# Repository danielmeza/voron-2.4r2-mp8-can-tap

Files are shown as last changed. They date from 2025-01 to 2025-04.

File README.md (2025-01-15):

# voron-2.4r2-mp8-can-tap
Klipper configuration for the Voron 2.4r2 Formbot kit with BTT RP2040, and TAP.

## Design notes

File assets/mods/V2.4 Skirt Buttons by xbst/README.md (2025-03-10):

# Voron V2.4 Skirt Buttons Mod
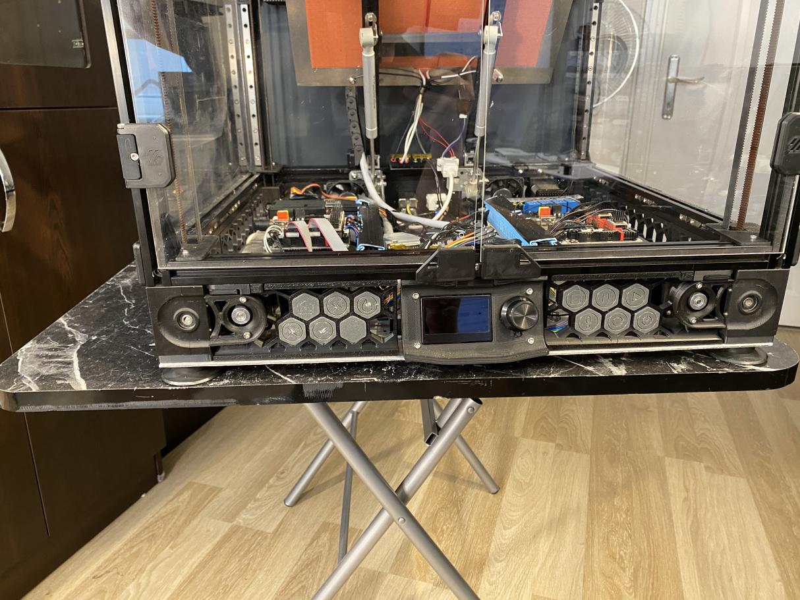
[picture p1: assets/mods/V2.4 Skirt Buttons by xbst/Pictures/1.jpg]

## Switches Needed
|Printer Size| Qty Needed |
|--|--|
| 350 | 12 |
| 300 | 8 |
| 250 | 4 |

You need 12*12mm 5mm tactile switches. Make sure they are through hole, not SMD! Here are a few examples:
Amazon: https://amzn.to/3788dfZ
Aliexpress: https://s.click.aliexpress.com/e/_eKCJlo

## Wiring
Put the switches in the hexagons, bend the legs of the switches.
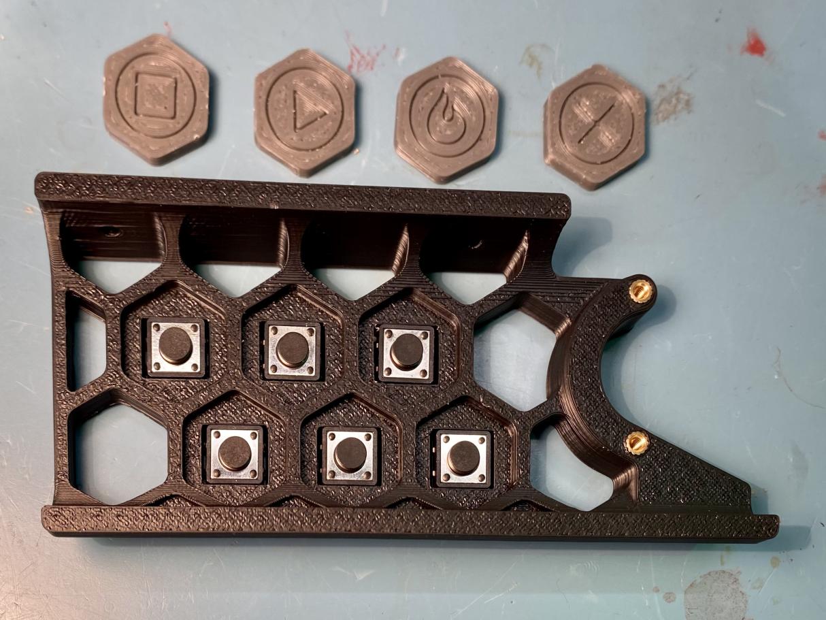
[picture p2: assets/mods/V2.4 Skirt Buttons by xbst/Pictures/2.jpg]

Wire one side of the switches together, connect to the mcu or Pi (depending on your config). Connect seperate wires to the opposite sides.
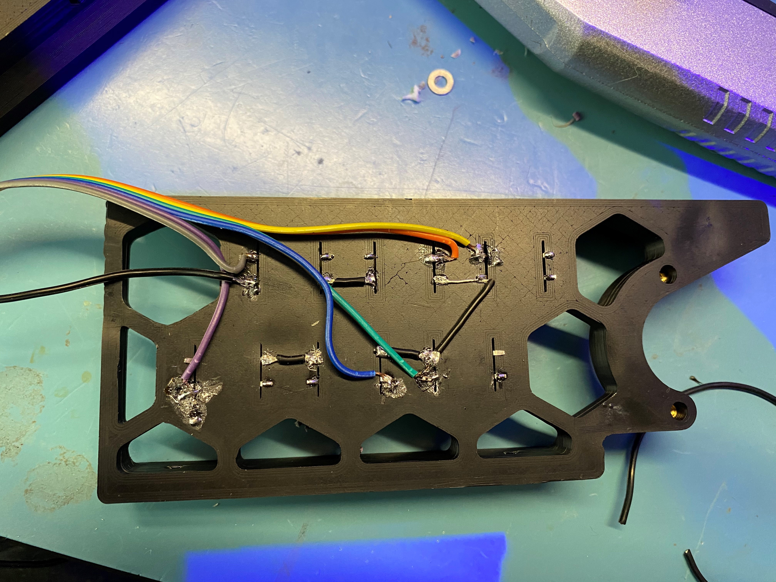
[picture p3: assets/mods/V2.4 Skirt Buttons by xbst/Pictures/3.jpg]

I recommend using hot glue to keep the wires in place. Otherwise you may disconnect the solder joints, or worse, break the legs of the switches when installing by accident.
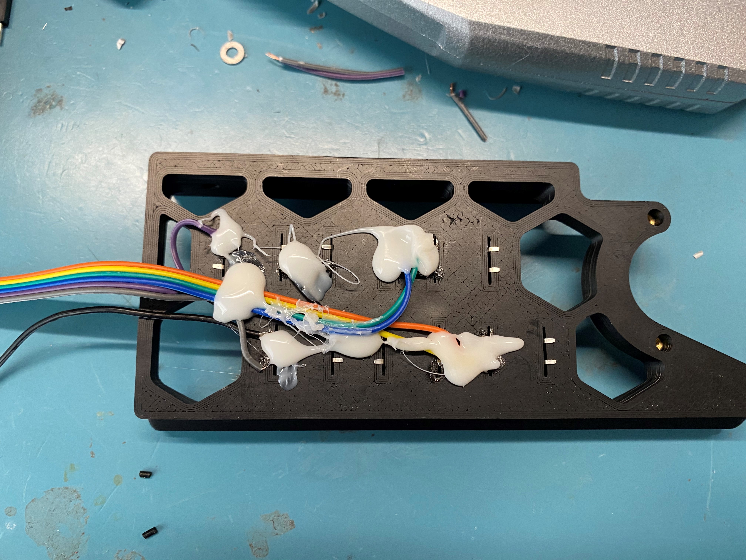
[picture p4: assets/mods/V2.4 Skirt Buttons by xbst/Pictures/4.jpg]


## Gluing The Buttons
I recommend using hot glue for attaching the printed button caps to the switches. You can also use super glue, but you may need to space the caps by putting a washer in between as hot glue is thicker.

You may need to cut the elephant foot if the buttons get stuck when pressed.

## Config Options
You have 2 choices: Using FW of your 3D printer (like Klipper), or using Octoprint's Enclosure plugin.

### Config for Klipper
Here is the relevant config info from [GitHub page of Klipper](https://github.com/KevinOConnor/klipper/blob/master/config/example-extras.cfg).

    # Execute gcode when a button is pressed or released (or when a pin
    # changes state). You can check the state of the button by using
    # QUERY_BUTTON button=my_gcode_button
    #[gcode_button my_gcode_button]
    #pin:
    # The pin on which the button is connected. This parameter must be
    # provided.
     #press_gcode:
    # A list of G-Code commands to execute when the button is pressed.
    # G-Code templates are supported. This parameter must be provided.
    #release_gcode:
    # A list of G-Code commands to execute when the button is released.
    # G-Code templates are supported. The default is to not run any
    # commands on a button release.

### Config for Octoprint
1. Install the plugin "Enclosure Plugin"
2. Configure based on the info on this page: https://github.com/vitormhenrique/OctoPrint-Enclosure

## Icons used
 https://www.iconfinder.com/iconsets/arrows-elements-outline
 Licensed under: https://creativecommons.org/licenses/by/3.0/

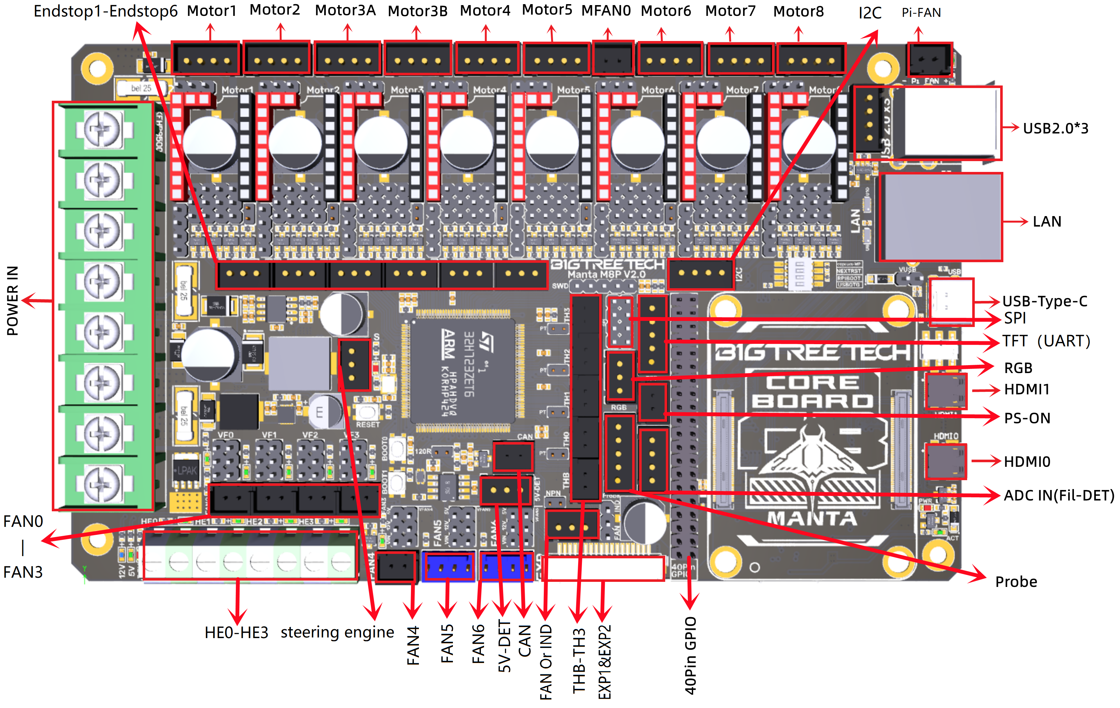
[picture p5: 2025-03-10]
docs/Manta MP8 v2/M8P V2.0-connect.png

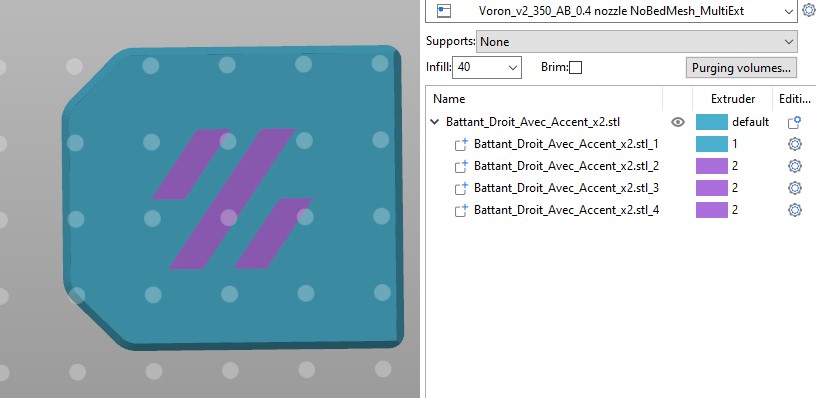
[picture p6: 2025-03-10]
assets/mods/Removable Doors by ElPoPo/Images/MMU.jpg

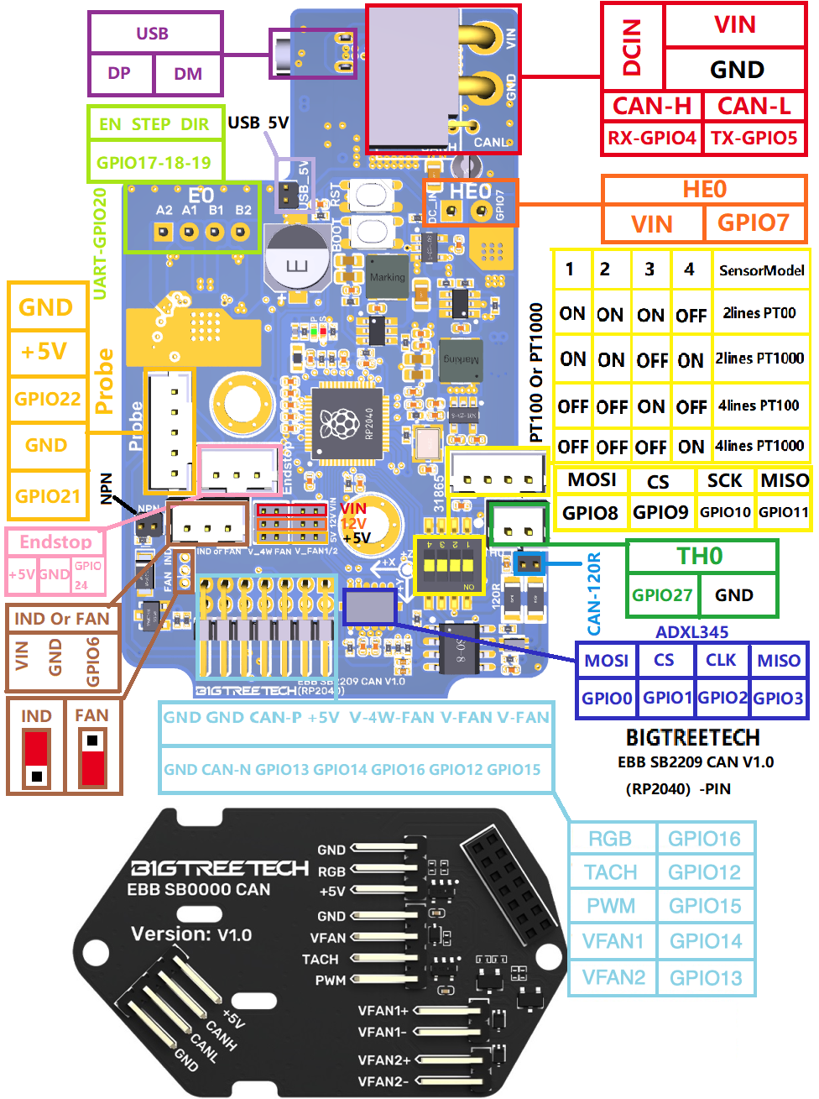
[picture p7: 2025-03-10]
docs/EBB RP2040 CAN/EBB SB2209 CAN V1.0（RP2040）-Pin.png

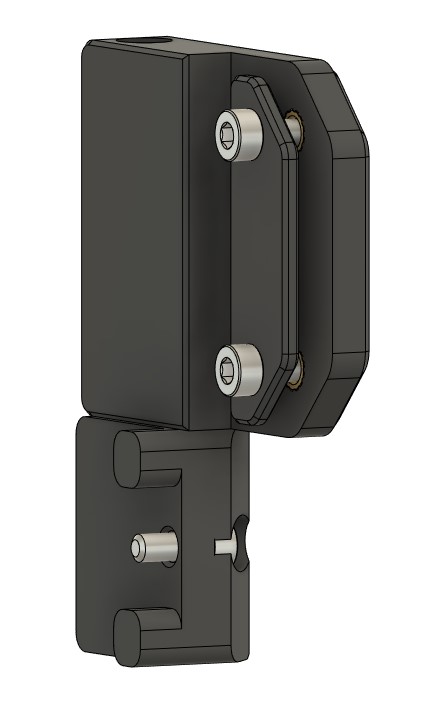
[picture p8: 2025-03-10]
assets/mods/Removable Doors by ElPoPo/Images/Charniere_Ar.jpg

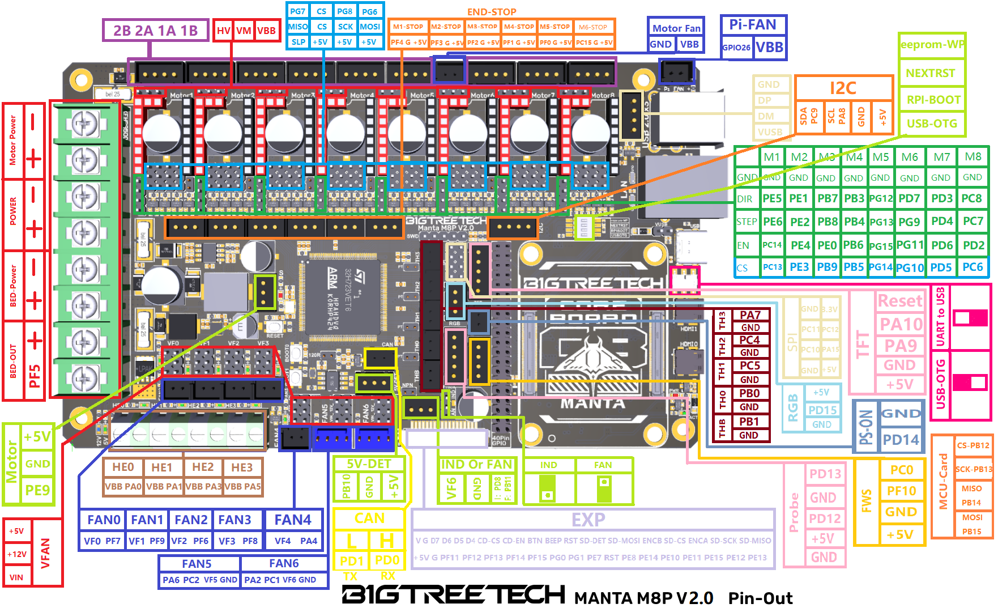
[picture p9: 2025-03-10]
docs/Manta MP8 v2/BIGTREETECH MANTA M8P V2.0 PinOut.png

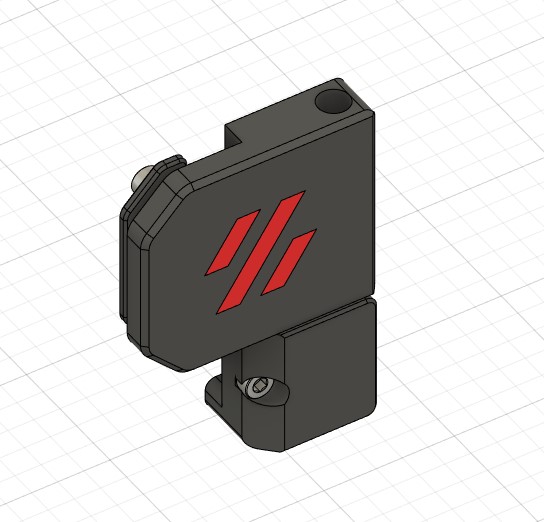
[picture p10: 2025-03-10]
assets/mods/Removable Doors by ElPoPo/Images/Charniere_Av.jpg

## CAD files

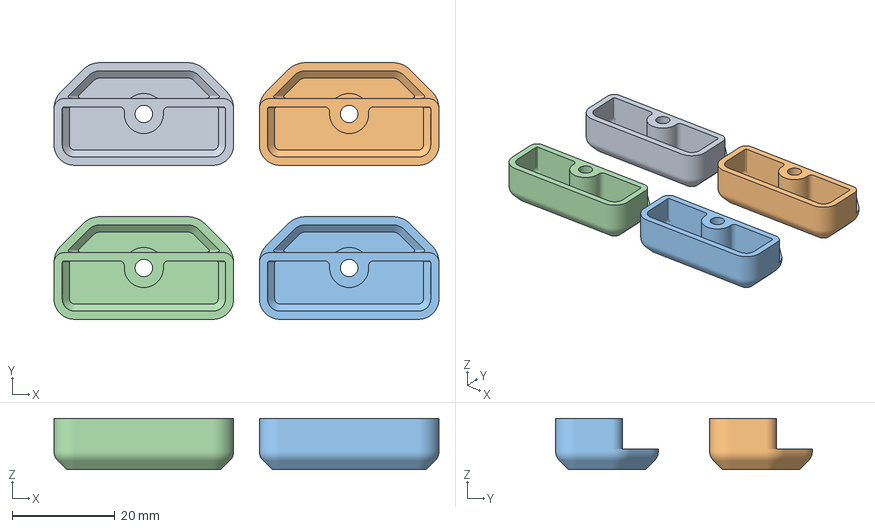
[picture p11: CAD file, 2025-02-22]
assets/cura stls/pannel mounting/CFFFP_midspan_panel_clip_6mm_x8.3mf
75.0 x 50.0 x 10.00 mm
midspan_panel_clip_6mm_x8.stl
midspan_panel_clip_6mm_x8.stl(1)
midspan_panel_clip_6mm_x8.stl(2)
midspan_panel_clip_6mm_x8.stl(3)

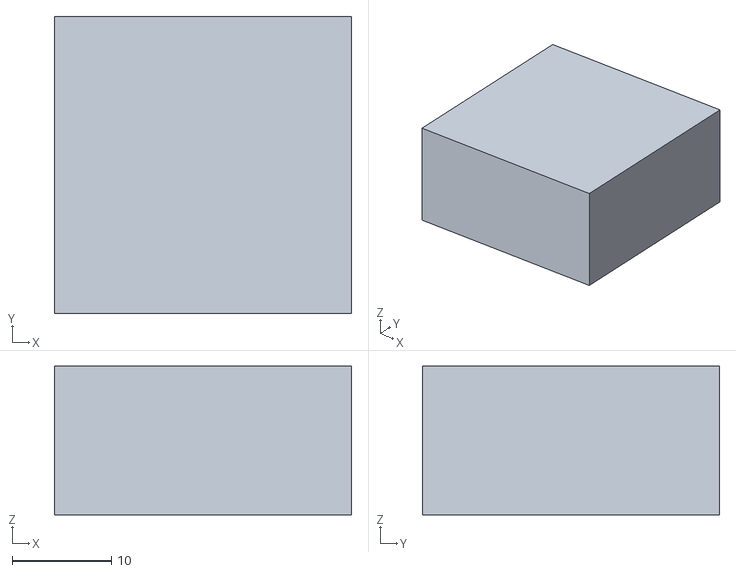
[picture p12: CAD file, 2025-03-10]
assets/mods/nozzle_clean/CornerSupport.stl
30.0 x 30.0 x 15.0

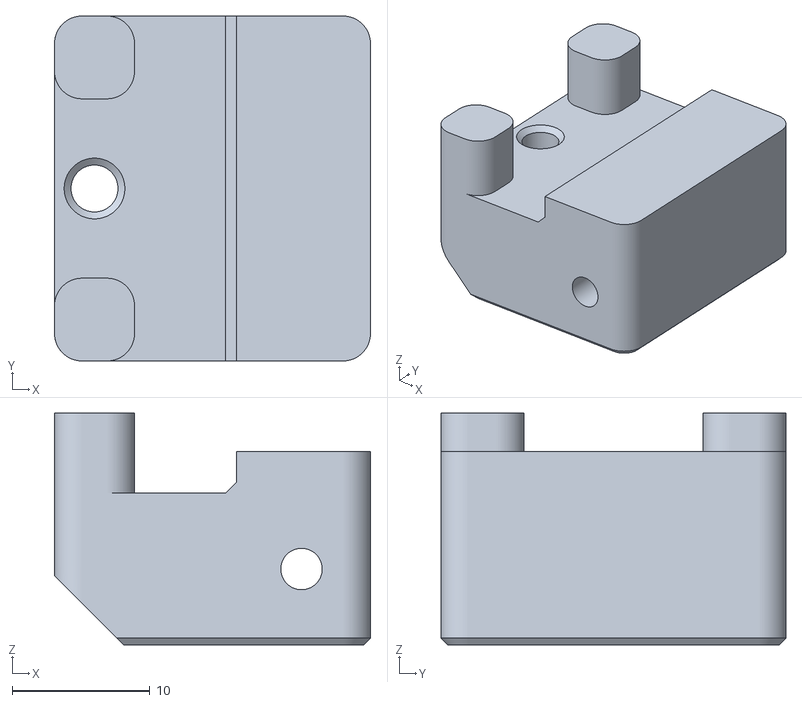
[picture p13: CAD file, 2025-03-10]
assets/mods/Removable Doors by ElPoPo/STL/Hinge_x4.stl
22.9 x 25.0 x 16.8

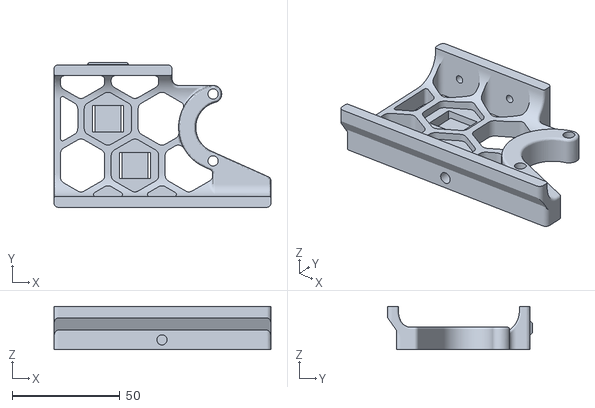
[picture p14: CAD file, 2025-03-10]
assets/mods/V2.4 Skirt Buttons by xbst/250/250_mirror.stl
100.5 x 67.0 x 20.0

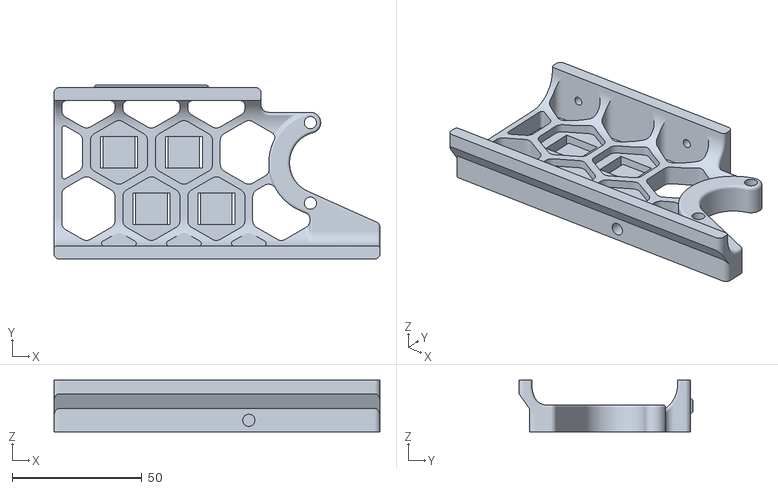
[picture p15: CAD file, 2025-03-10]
assets/mods/V2.4 Skirt Buttons by xbst/300/300_mirror.stl
125.5 x 67.0 x 20.0

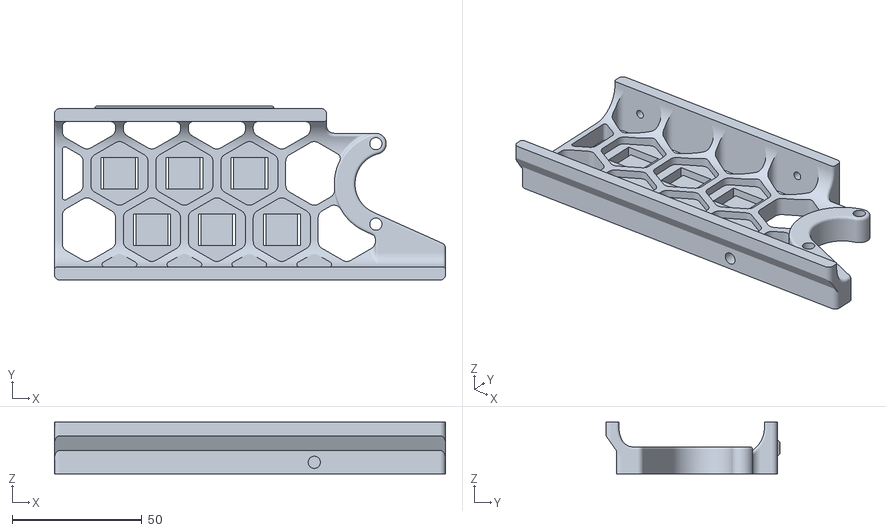
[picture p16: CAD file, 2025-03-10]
assets/mods/V2.4 Skirt Buttons by xbst/350/350_mirror.stl
150.5 x 67.0 x 20.0

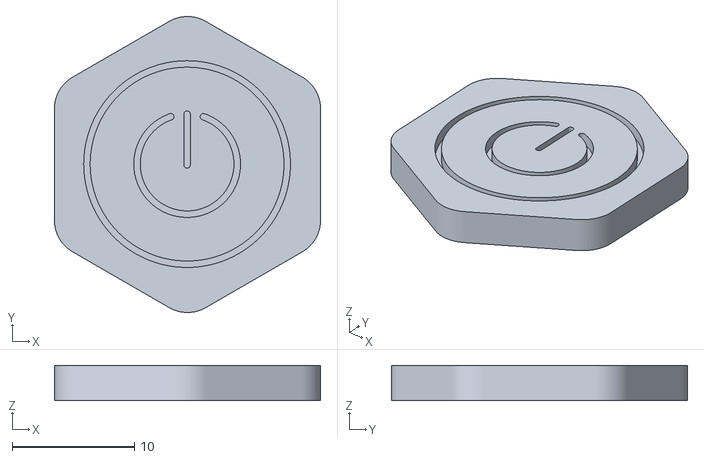
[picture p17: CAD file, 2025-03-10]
assets/mods/V2.4 Skirt Buttons by xbst/Buttons/Power.stl
21.8 x 24.2 x 2.90

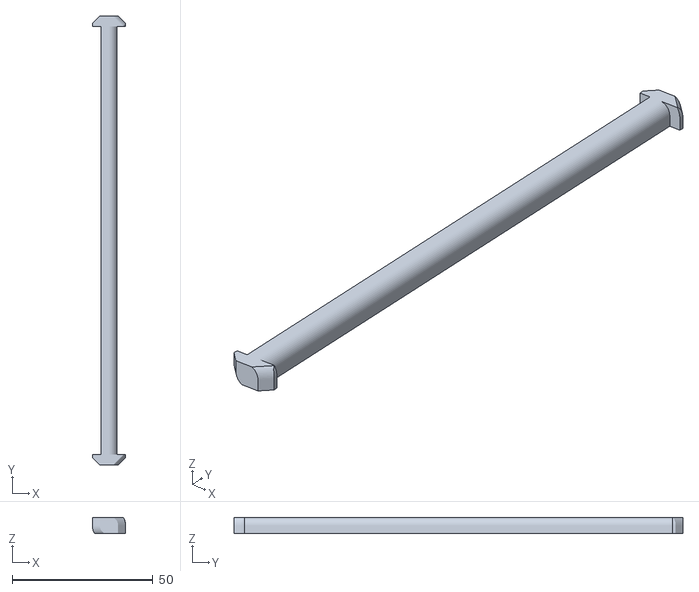
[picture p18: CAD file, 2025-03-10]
tools/z-locks-150.stl
11.8 x 159.6 x 5.81

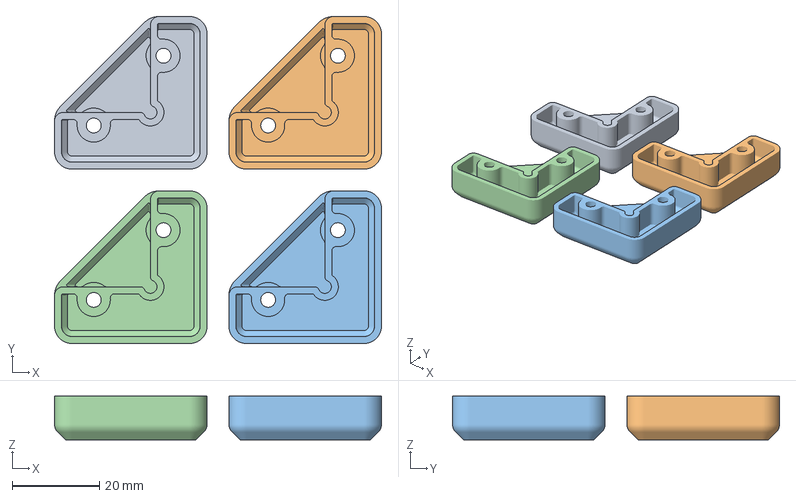
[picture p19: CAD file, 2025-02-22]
assets/cura stls/pannel mounting/UCP_corner_panel_clip_6mm_x8.3mf
75.0 x 75.0 x 10.00 mm
corner_panel_clip_6mm_x8.stl
corner_panel_clip_6mm_x8.stl(1)
corner_panel_clip_6mm_x8.stl(2)
corner_panel_clip_6mm_x8.stl(3)

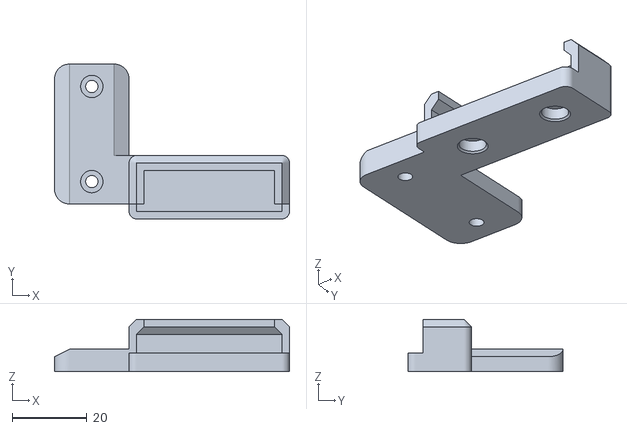
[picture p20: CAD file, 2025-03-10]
assets/mods/nozzle_clean/Brush Holder.stl
63.0 x 41.5 x 14.0

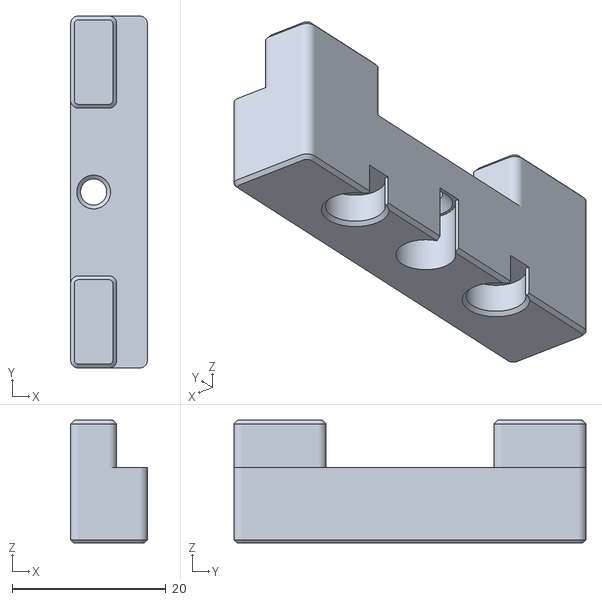
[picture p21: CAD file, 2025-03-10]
assets/mods/Removable Doors by ElPoPo/STL/latch_x2.stl
10.0 x 45.9 x 16.0

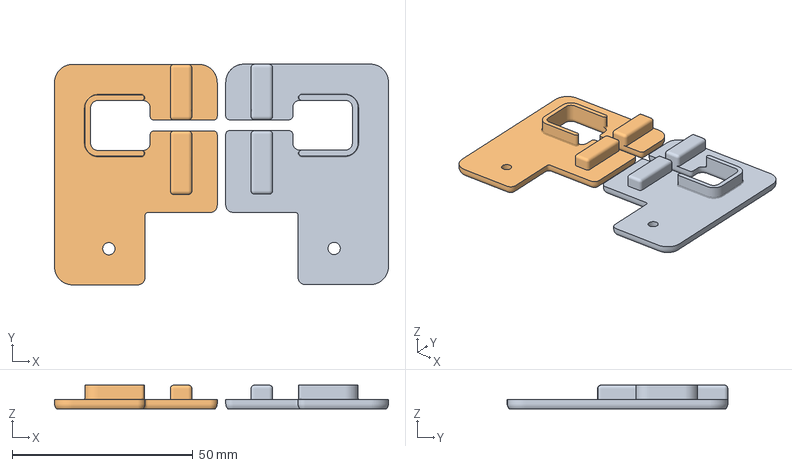
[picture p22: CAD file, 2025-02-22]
assets/cura stls/pannel mounting/UCP_z_belt_cover_b_x2.3mf
92.4 x 61.1 x 6.60 mm
z_belt_cover_b_x2.stl
z_belt_cover_a_x2.stl

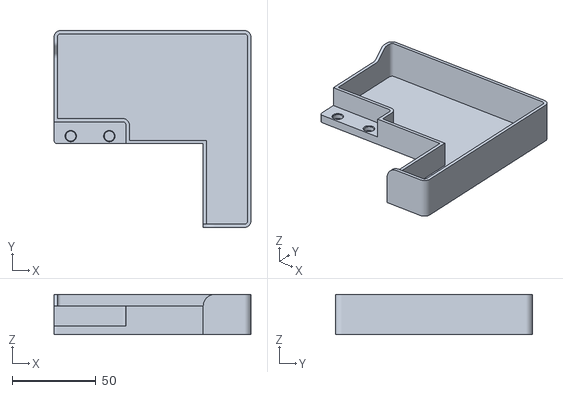
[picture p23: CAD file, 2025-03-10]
assets/mods/nozzle_clean/350mm_Bucket.stl
117.5 x 117.5 x 24.0

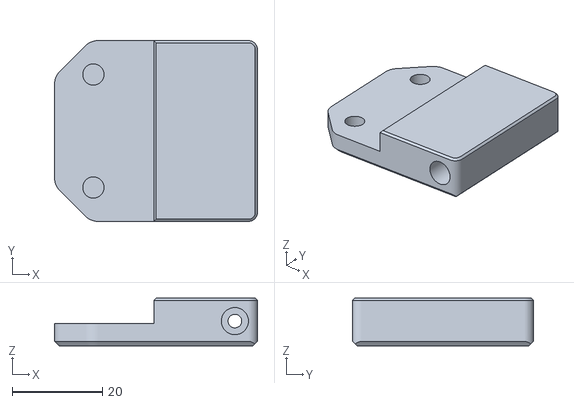
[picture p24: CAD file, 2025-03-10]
assets/mods/Removable Doors by ElPoPo/STL/Right_Leaf_x2.stl
44.9 x 40.0 x 10.6

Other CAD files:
assets/mods/V2.4 Skirt Buttons by xbst/250/250.stl
assets/mods/V2.4 Skirt Buttons by xbst/300/300.stl
assets/mods/V2.4 Skirt Buttons by xbst/350/350.stl
assets/mods/V2.4 Skirt Buttons by xbst/Buttons/flm_sw.stl
assets/cura stls/pannel mounting/CFFFP_door_hinge_x6.3mf
assets/cura stls/pannel mounting/CFFFP_handle_b_x2.3mf
assets/cura stls/pannel mounting/CFFFP_latch_x2.3mf
assets/mods/Removable Doors by ElPoPo/STL/Backplate_x4.stl
assets/mods/Removable Doors by ElPoPo/STL/Left_Leaf_VHB_With_Accent_x2.stl
assets/mods/Removable Doors by ElPoPo/STL/Left_Leaf_VHB_x2.stl
assets/mods/Removable Doors by ElPoPo/STL/Left_Leaf_With_Accent_x2.stl
assets/mods/Removable Doors by ElPoPo/STL/Left_Leaf_x2.stl
assets/mods/Removable Doors by ElPoPo/STL/Right_Leaf_VHB_With_Accent_x2.stl
assets/mods/Removable Doors by ElPoPo/STL/Right_Leaf_VHB_x2.stl
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

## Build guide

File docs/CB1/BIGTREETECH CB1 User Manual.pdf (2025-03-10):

Shenzhen Big Tree Technology Co., Ltd.

## BIGTREETECH

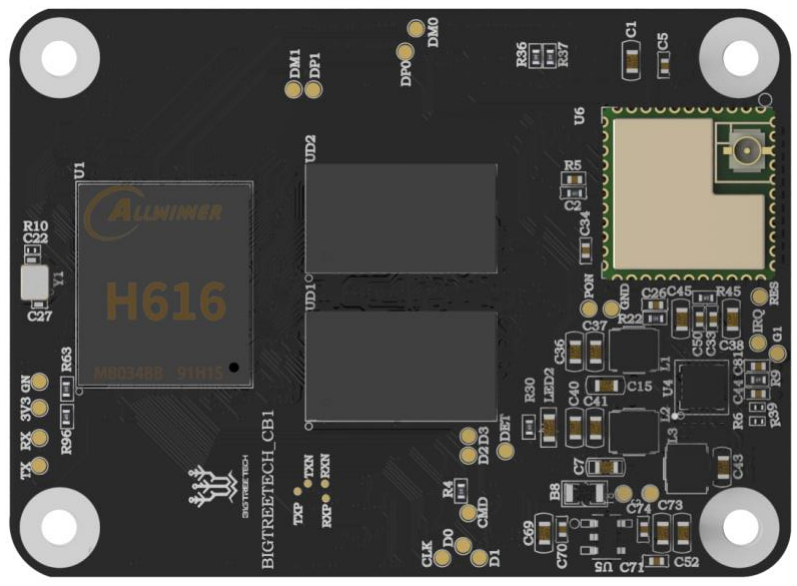
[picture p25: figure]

1 / 22

# BIGTREETECH

CB1

# User Manual

## BIGTREETECH

2 / 22

# CONTENTS

## BIGTREETECH

3 / 22

# Revision History

Version | Revisions | Date
01.00 | Original | 2022/09/20

## BIGTREETECH

4 / 22

# 1. Product Profile

### The BIGTREETECH CB1 is launched to provide a great solution to the insane shortage of Raspberry Pi CM4. It outputs signals to the motherboard via the fast and

convenient two 100 pins micro BTB connection header, including 100M Ethernet, HDMI, etc. Also, onboard 2.4G WiFi.

## 1.1 Feature Highlights

### 1. CPU: ALLWINNER H616, Quad-core Cortex-A53 @1.5GHz

### 2. GPU: Mali G31 MP2, Support OpenGL3.2

### 3. RAM: 512MB/1GB DDR3L SDRAM

### 4. Display: Compatible with HDMI2.0A Interface, Support 4K Displays

### 5. Compatible with USB2.0 Interface

### 6. Support 100M Ethernet + 100M WiFi

7. Having the same BTB header as the Raspberry Pi CM4.

## 1.2 Specifications

### 1. Product Size: 40mm x 55mm

### 2. Mounting Size: 33mm x 48mm

### 3. Input Voltage: 5V±5%/2A

### 4. Output Voltage: 3.3V±2%/100mA

### 5. Output Voltage: 1.8V±2%/100mA

### 6. WiFi: 2.4G/802.11 b/g/n

## BIGTREETECH

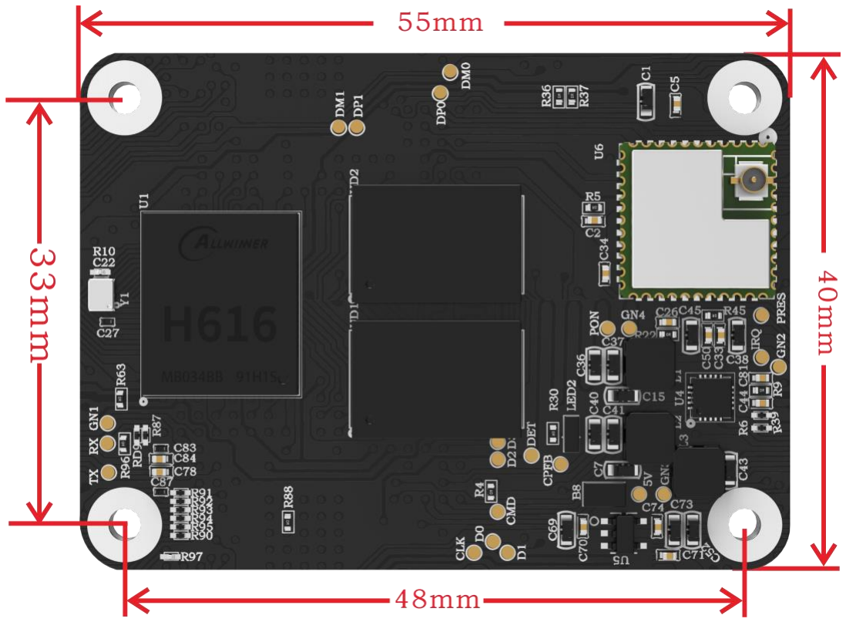
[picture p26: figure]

5 / 22

## 1.3 Dimensions

# 2 Peripheral Port

## 2.1 Pin

PIN | Connector | Signal | Description
1 | A connector_01 | GND
2 | A connector_02 | GND
3 | A connector_03 | NC
4 | A connector_04 | EPHY-TXP | Ethernet TX Positive
5 | A connector_05 | NC
6 | A connector_06 | EPHY-TXN | Ethernet TX Negative
7 | A connector_07 | GND
8 | A connector_08 | GND
9 | A connector_09 | NC
10 | A connector_10 | EPHY-RXP | Ethernet RX Positive
11 | A connector_11 | NC
12 | A connector_12 | EPHY-RXN | Ethernet RX Negative
13 | A connector_13 | GND

## BIGTREETECH

6 / 22

14 | A connector_14 | GND
15 | A connector_15 | LINK_LED | Ethernet LED
16 | A connector_16 | NC
17 | A connector_17 | SPD_LED | Ethernet LED
18 | A connector_18 | NC
19 | A connector_19 | NC
20 | A connector_20 | NC
21 | A connector_21 | SYS-LED | System work light
22 | A connector_22 | GND
23 | A connector_23 | GND
24 | A connector_24 | PC15 | 3.3V IO(CB1 V2.1 is 1.8v )
25 | A connector_25 | PC8 | 3.3V IO(CB1 V2.1 is 1.8v )
26 | A connector_26 | PC6 | 3.3V IO(CB1 V2.1 is 1.8v )
27 | A connector_27 | PH10 | 3.3V IO
28 | A connector_28 | NC
29 | A connector_29 | NC
30 | A connector_30 | PG6 | 3.3V IO
31 | A connector_31 | PG9 | 3.3V IO
32 | A connector_32 | GND
33 | A connector_33 | GND
34 | A connector_34 | NC
35 | A connector_35 | PG7 | 3.3V IO
36 | A connector_36 | NC
37 | A connector_37 | PG8 | 3.3V IO
38 | A connector_38 | PH6 | 3.3V IO
39 | A connector_39 | NC | 3.3V IO
40 | A connector_40 | PH8 | 3.3V IO
41 | A connector_41 | NC
42 | A connector_42 | GND
43 | A connector_43 | GND
44 | A connector_44 | PH7 | 3.3V IO
45 | A connector_45 | PC9 | 3.3V IO(CB1 V2.1 is 1.8v )
46 | A connector_46 | PC10 | 3.3V IO(CB1 V2.1 is 1.8v )
47 | A connector_47 | PC11 | 3.3V IO(CB1 V2.1 is 1.8v )
48 | A connector_48 | PC12 | 3.3V IO(CB1 V2.1 is 1.8v )
49 | A connector_49 | PC13 | 3.3V IO(CB1 V2.1 is 1.8v )
50 | A connector_50 | PC14 | 3.3V IO(CB1 V2.1 is 1.8v )
51 | A connector_51 | SoC_RX | DEBUG UART
52 | A connector_52 | GND
53 | A connector_53 | GND
54 | A connector_54 | PC7 | 3.3V IO(CB1 V2.1 is 1.8v )
55 | A connector_55 | SoC_TX | DEBUG UART
56 | A connector_56 | NC
57 | A connector_57 | SDC0-CLK | SDCARD Clock signal

## BIGTREETECH

7 / 22

58 | A connector_58 | NC
59 | A connector_59 | GND
60 | A connector_60 | GND
61 | A connector_61 | SDC0-D3 | SDCARD Data3 signal
62 | A connector_62 | SDC0-CMD | SDCARD CMD signal
63 | A connector_63 | SDC0-D0 | SDCARD Data0 signal
64 | A connector_64 | PG11 | 3.3V IO
65 | A connector_65 | GND
66 | A connector_66 | GND
67 | A connector_67 | SDC0-D1 | SDCARD Data1 signal
68 | A connector_68 | PG12 | 3.3V IO
69 | A connector_69 | SDC0-D2 | SDCARD Data2 signal
70 | A connector_70 | PG13 | 3.3V IO
71 | A connector_71 | GND
72 | A connector_72 | PG14 | 3.3V IO
73 | A connector_73 | PG16 | 3.3V IO
74 | A connector_74 | GND
75 | A connector_75 | NC
76 | A connector_76 | SDC0-DET | SDCARD detect
77 | A connector_77 | VCC_5V | 5V IN /2A
78 | A connector_78 | NC
79 | A connector_79 | VCC_5V | 5V IN /2A
80 | A connector_80 | NC
81 | A connector_81 | VCC_5V | 5V IN /2A
82 | A connector_82 | NC
83 | A connector_83 | VCC_5V | 5V IN /2A
84 | A connector_84 | 3V3 | 3.3V out /200mA
85 | A connector_85 | VCC_5V | 5V IN /2A
86 | A connector_86 | 3V3 | 3.3V out /200mA
87 | A connector_87 | VCC_5V | 5V IN /2A
88 | A connector_88 | 1V8 | 1.8V out /100mA
89 | A connector_89 | NC
90 | A connector_90 | 1V8 | 1.8V out /100mA
91 | A connector_91 | NC
92 | A connector_92 | PWRON | Power switch (useless)
93 | A connector_93 | FEL | (useless)
94 | A connector_94 | NC
95 | A connector_95 | NC
96 | A connector_96 | NC
97 | A connector_97 | NC
98 | A connector_98 | GND
99 | A connector_99 | RECOVERY | Program download (useless)
100 | A connector_100 | AP-RESET | power reset (useless)
101 | B connector_1 | NC

## BIGTREETECH

8 / 22

102 | B connector_2 | NC
103 | B connector_3 | USB1-DM | HOST USB1
104 | B connector_4 | LINEOUTL
105 | B connector_5 | USB1-DP | HOST USB1
106 | B connector_6 | LINEOUTR
107 | B connector_7 | GND
108 | B connector_8 | GND
109 | B connector_9 | NC
110 | B connector_10 | NC
111 | B connector_11 | TV_OUT | CVBS OUT
112 | B connector_12 | NC
113 | B connector_13 | GND
114 | B connector_14 | GND
115 | B connector_15 | NC
116 | B connector_16 | NC
117 | B connector_17 | NC
118 | B connector_18 | NC
119 | B connector_19 | GND
120 | B connector_20 | GND
121 | B connector_21 | NC
122 | B connector_22 | NC
123 | B connector_23 | NC
124 | B connector_24 | NC
125 | B connector_25 | GND
126 | B connector_26 | GND
127 | B connector_27 | NC
128 | B connector_28 | USB3-DM | HOST USB3
129 | B connector_29 | NC
130 | B connector_30 | USB3-DP | HOST USB3
131 | B connector_31 | GND
132 | B connector_32 | GND
133 | B connector_33 | NC
134 | B connector_34 | USB2-DM | HOST USB2
135 | B connector_35 | NC
136 | B connector_36 | USB2-DP | HOST USB2
137 | B connector_37 | GND
138 | B connector_38 | GND
139 | B connector_39 | NC
140 | B connector_40 | USB0-DM | OTG USB
141 | B connector_41 | NC
142 | B connector_42 | USB0-DP | OTG USB
143 | B connector_43 | NC
144 | B connector_44 | GND
145 | B connector_45 | NC

## BIGTREETECH

9 / 22

146 | B connector_46 | NC
147 | B connector_47 | NC
148 | B connector_48 | NC
149 | B connector_49 | NC
150 | B connector_50 | GND
151 | B connector_51 | HCEC | HDMI CEC
152 | B connector_52 | NC
153 | B connector_53 | HHPD | HDMI Hotplug
154 | B connector_54 | NC
155 | B connector_55 | GND
156 | B connector_56 | GND
157 | B connector_57 | NC
158 | B connector_58 | NC
159 | B connector_59 | NC
160 | B connector_60 | NC
161 | B connector_61 | GND
162 | B connector_62 | GND
163 | B connector_63 | NC
164 | B connector_64 | NC
165 | B connector_65 | NC
166 | B connector_66 | NC
167 | B connector_67 | GND
168 | B connector_68 | GND
169 | B connector_69 | NC
170 | B connector_70 | HTX2P | HDMI TX2 Positive.
171 | B connector_71 | NC
172 | B connector_72 | HTX2N | HDMI TX2 Negative.
173 | B connector_73 | GND
174 | B connector_74 | GND
175 | B connector_75 | NC
176 | B connector_76 | HTX1P | HDMI TX1 Positive.
177 | B connector_77 | NC
178 | B connector_78 | HTX1N | HDMI TX1 Negative.
179 | B connector_79 | GND
180 | B connector_80 | GND
181 | B connector_81 | NC
182 | B connector_82 | HTX0P | HDMI TX0 Positive.
183 | B connector_83 | NC
184 | B connector_84 | HTX0N | HDMI TX0 Negative.
185 | B connector_85 | GND
186 | B connector_86 | GND
187 | B connector_87 | NC
188 | B connector_88 | HTXCP | HDMI CLK Positive.
189 | B connector_89 | NC

## BIGTREETECH

10 / 22

190 | B connector_90 | HTXCN | HDMI CLK Negative.
191 | B connector_91 | GND
192 | B connector_92 | GND
193 | B connector_93 | NC
194 | B connector_94 | NC
195 | B connector_95 | NC
196 | B connector_96 | NC
197 | B connector_97 | GND
198 | B connector_98 | GND
199 | B connector_99 | HSDA | HDMI I2C
200 | B connector_100 | HSCL | HDMI I2C

## BIGTREETECH

# 3. Interface Introduction

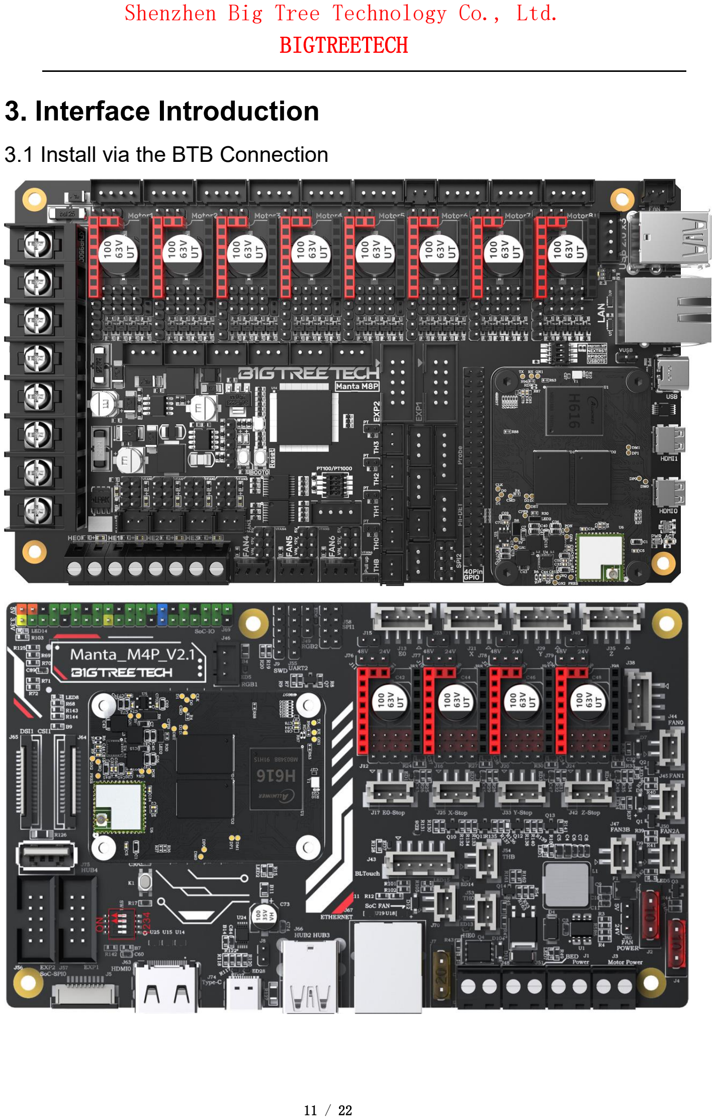
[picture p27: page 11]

11 / 22

## 3.1 Install via the BTB Connection

## BIGTREETECH

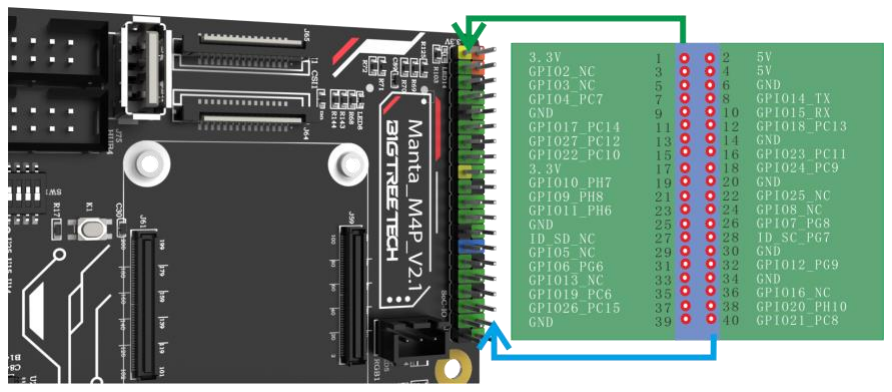
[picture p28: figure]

12 / 22

## 3.2 40 pins GPIO

When Manta series motherboard work with CB1, 40 pins GPIO is a custom IO arrangement, as shown in the figure below, Pin 7 is CB1's "PC7", and Pin 11 is CB1's "PC14". The GPIO number of CB1 corresponds to (Px–PA)*32 + Pin For example: PC7 = (PC–PA)*32 + 7 = 2 * 32 + 7 = 71 PH10 = (PH–PA)*32 + 10 = 7 * 32 + 10 = 234 PC7 is numbered in Klipper as pin: host: gpio71, PH10 as pin: host: gpio234

Note: The logic voltage of PC ports in V2.1 version (PC6, PC7, PC8, PC9, PC10, PC11, PC12, PC13, PC14, PC15): 1.8V;

The logic voltage of PC ports in V2.2 version (PC6, PC7, PC8, PC9, PC10, PC11, PC12, PC13, PC14, PC15): 3.3V.

## BIGTREETECH

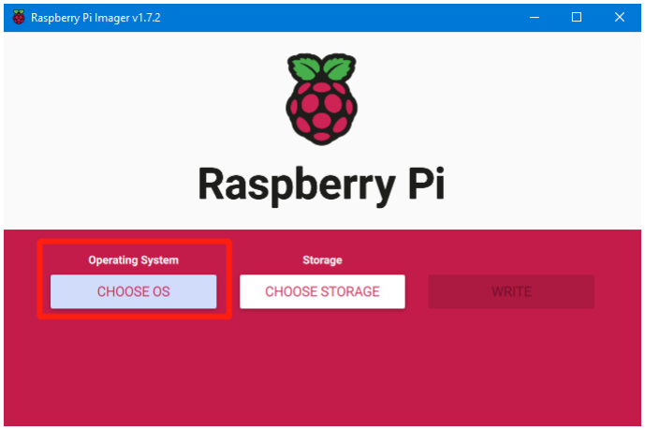
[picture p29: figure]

13 / 22

# 4. Write OS

## 4.1 Download the OS Image

### Please download and install the OS image we provided: https://github.com/bigtreetech/CB1/releases

## 4.2 Download and Install Writing Software

### The official Raspberry Pi Imager: https://www.raspberrypi.com/software/ balenaEtcher: https://www.balena.io/etcher/

Both of the above software can be used, just choose one to download and install.

## 4.3 Write OS

### 4.3.1 For Raspberry Pi Imager

a. Insert a MicroSD into your computer.
b. Choose OS.

## BIGTREETECH

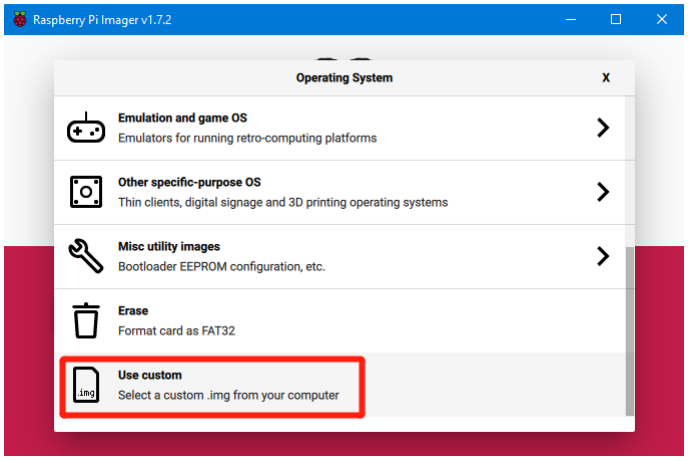
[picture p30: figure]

14 / 22

c. Select "Use custom", then select the image that you downloaded.

### d. Select the MicroSD card and click "WRITE" (WRITE the image will format the MicroSD card. Be careful not to select the wrong storage device, otherwise the data will be formatted.)

## BIGTREETECH

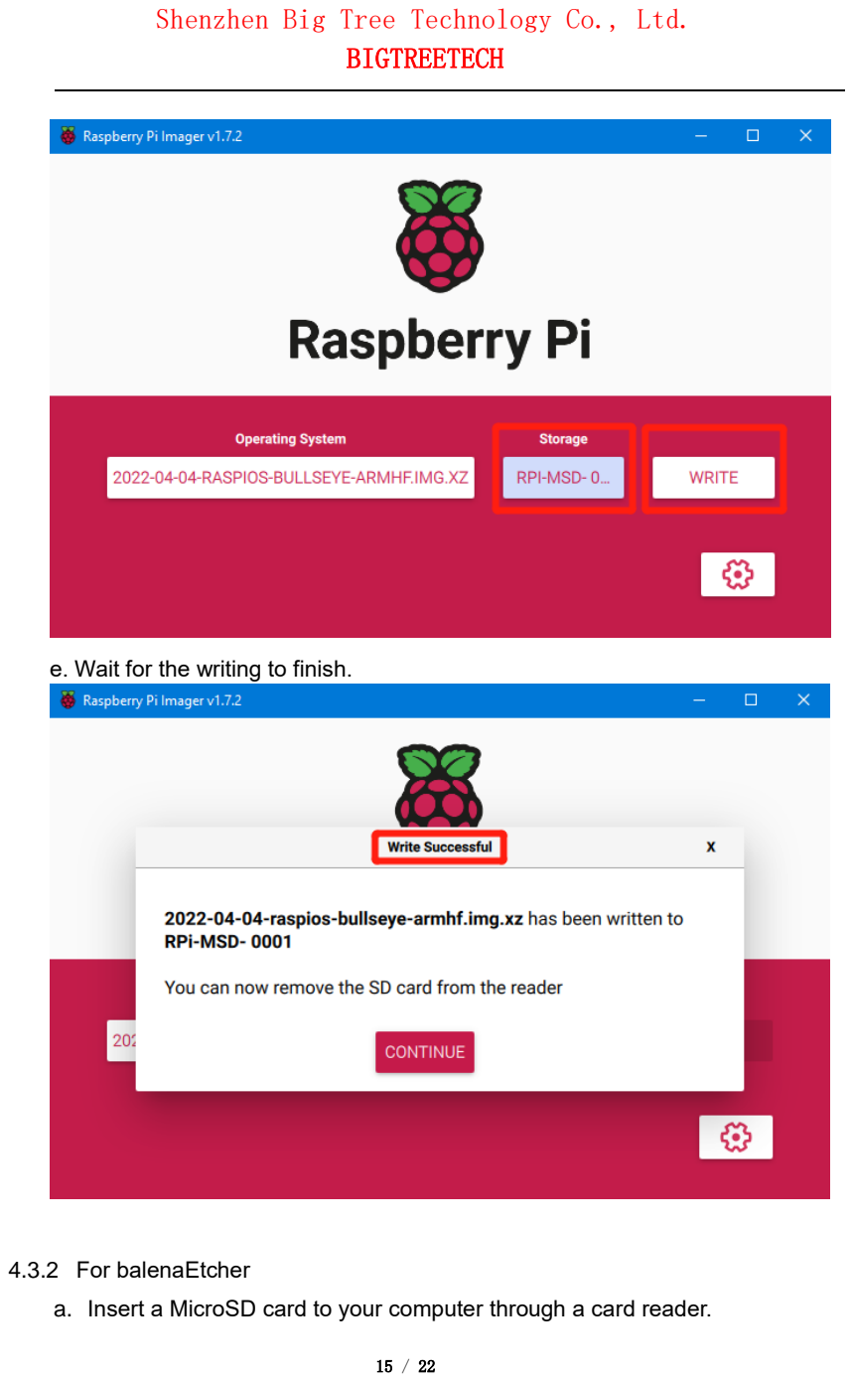
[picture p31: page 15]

15 / 22

e. Wait for the writing to finish.

### 4.3.2 For balenaEtcher

a. Insert a MicroSD card to your computer through a card reader.

## BIGTREETECH

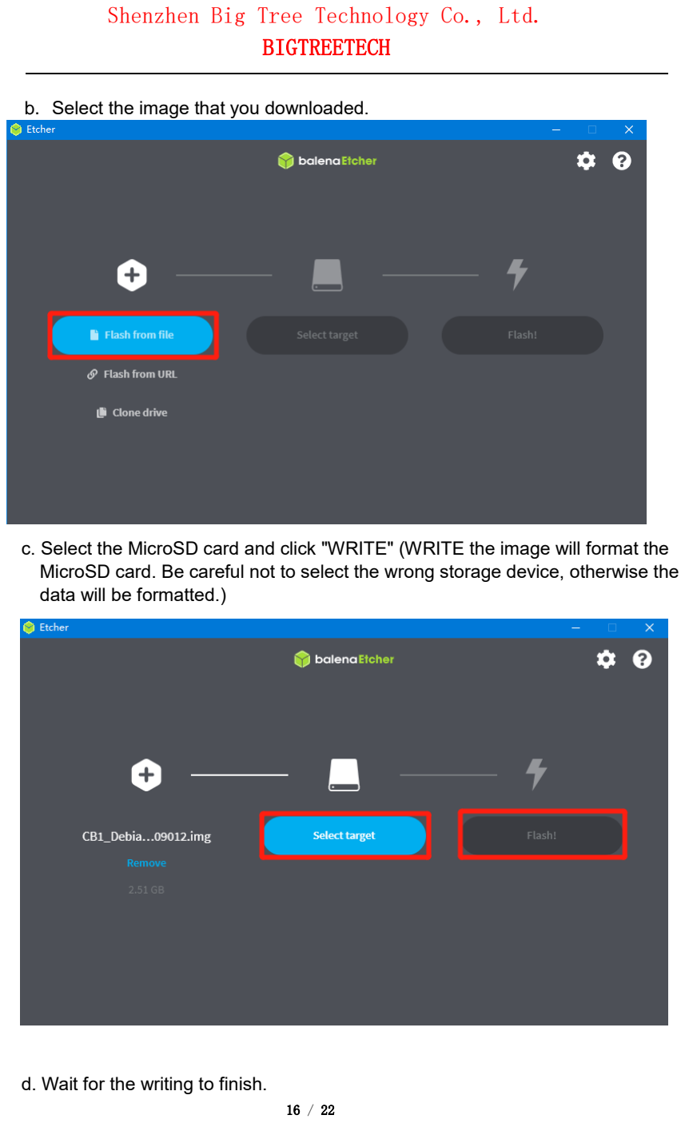
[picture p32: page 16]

16 / 22

b. Select the image that you downloaded.

### c. Select the MicroSD card and click "WRITE" (WRITE the image will format the MicroSD card. Be careful not to select the wrong storage device, otherwise the data will be formatted.)

d. Wait for the writing to finish.

## BIGTREETECH

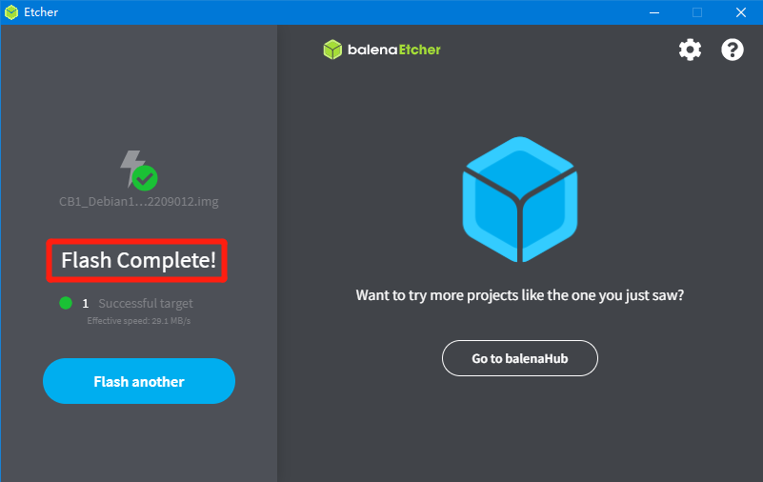
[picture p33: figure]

17 / 22

## BIGTREETECH

# 5. Configure Network

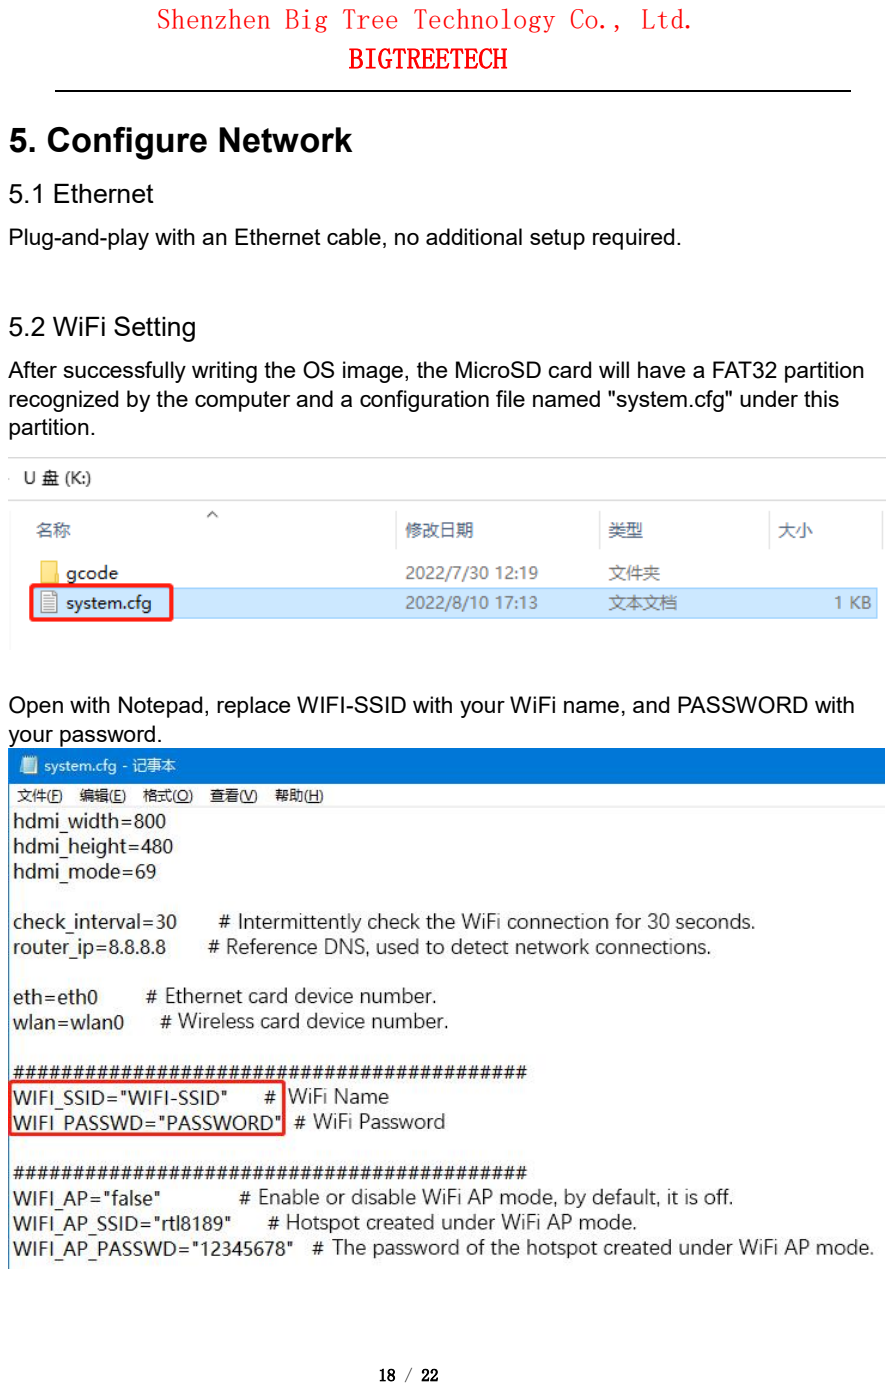
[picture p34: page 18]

18 / 22

## 5.1 Ethernet

Plug-and-play with an Ethernet cable, no additional setup required.

## 5.2 WiFi Setting

### After successfully writing the OS image, the MicroSD card will have a FAT32 partition recognized by the computer and a configuration file named "system.cfg" under this

partition.

### Open with Notepad, replace WIFI-SSID with your WiFi name, and PASSWORD with

your password.

## BIGTREETECH

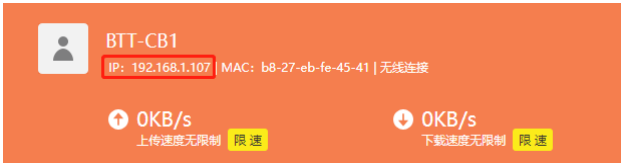
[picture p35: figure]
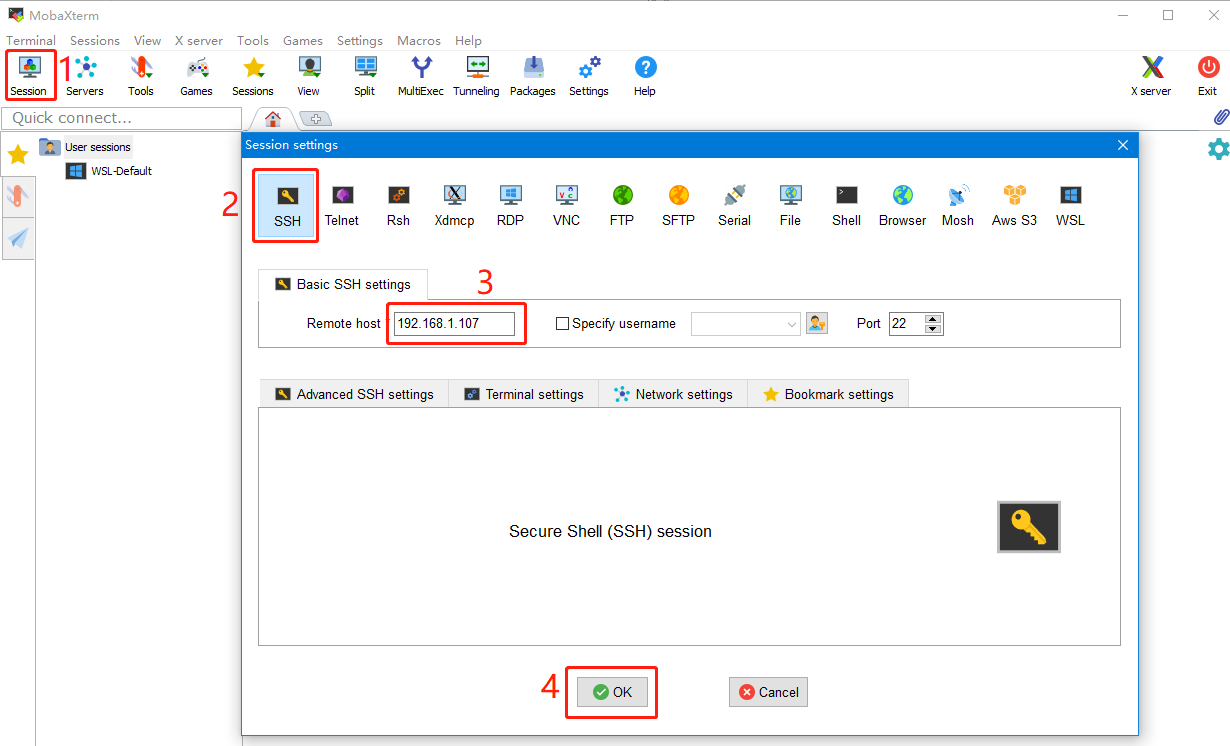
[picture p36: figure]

19 / 22

# 6. Configure Motherboard

## 6.1 SSH Connect to Device with CB1 Installed

### 1. Install the SSH application Mobaxterm: https://mobaxterm.mobatek.net/download-home-edition.html (https://mobaxterm.mobatek.net/download-home-edition.html)

### 2. Insert the MicroSD card to the motherboard, and wait for the system to load after

power on, approx. 1-2 minutes.

### 3. The device with CB1 installed will automatically be assigned an IP after being

successfully connected to the network.

4. Find the IP address on your router page.

### 5. Open Mobaxterm and click "Session", and click "SSH", enter the IP you got in step 3 into Remote host, and click "OK". (Note: your computer and the printer needs to be in the same network.)

## BIGTREETECH

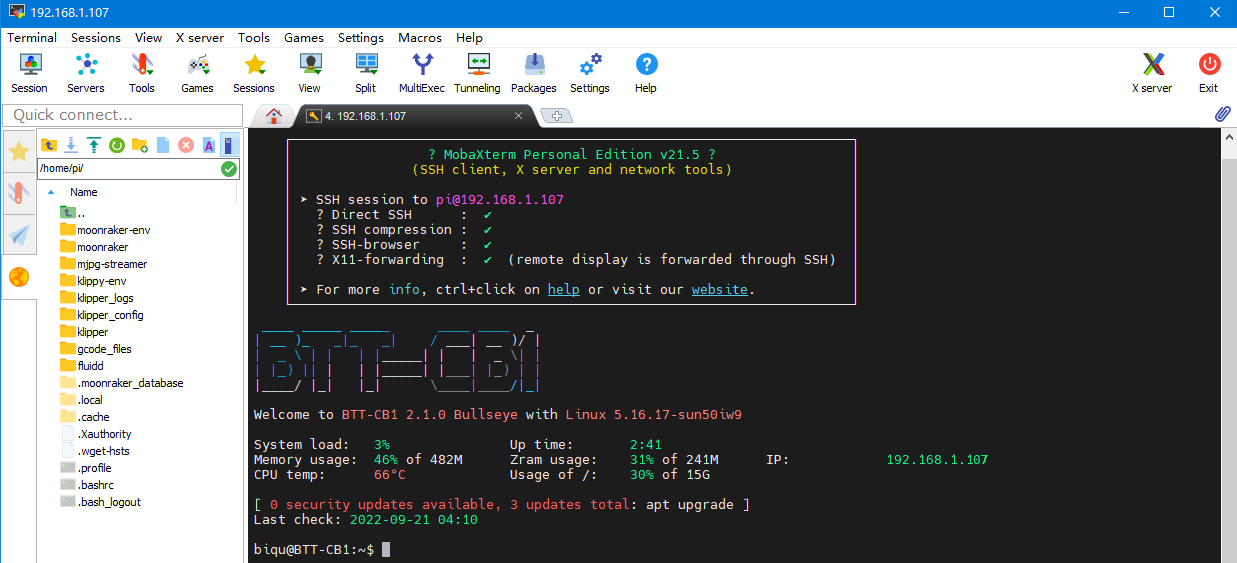
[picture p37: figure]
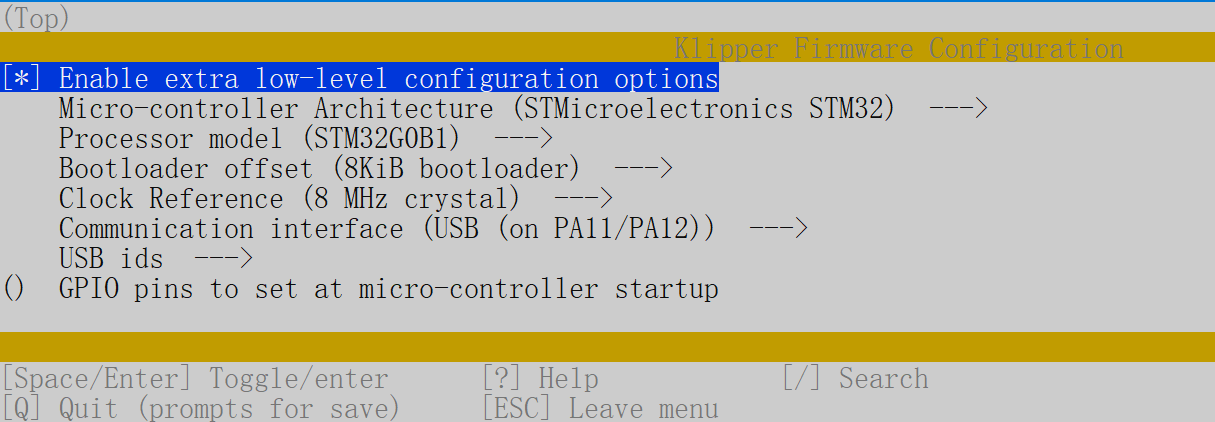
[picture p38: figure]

20 / 22

6. Login as: biqu, password: biqu.

## 6.2 Compile MCU Firmware

1. After SSH is successfully connected to the device with CB1 installed, enter in the terminal: cd ~/klipper/ make menuconfig Compile the firmware with the corresponding motherboard configuration, here is the Manta M4P example: * [*] Enable extra low-level configuration options * Micro-controller Architecture (STMicroelectronics STM32) ---> * Processor model (STM32G0B1) ---> * Bootloader offset (8KiB bootloader) ---> * Clock Reference (8 MHz crystal) ---> * Communication interface (USB (on PA11/PA12)) --->

## BIGTREETECH

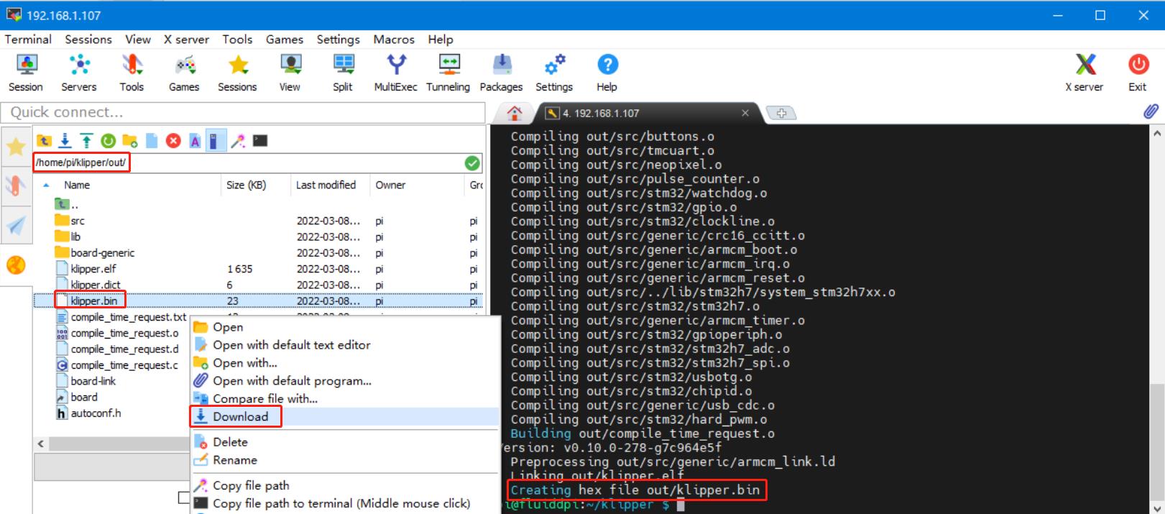
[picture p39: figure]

21 / 22

2. Press q to exit, and Yes when asked to save the configuration.
3. Run | make | to compile firmware, "klipper.bin" file will be generated in
home/pi/klipper/out folder when | make | is finished, download it onto your
computer using the SSH application.

## BIGTREETECH

22 / 22

# 7. Cautions

### - All unplugging and plugging operations should be performed under the condition of

power off, except for HDMI, USB, and RJ45.

### - Pay attention to the heat dissipation of CB1. If the running application consumes

too many system resources, the CB1 will get hot quite seriously.

If you need other resources for this product, please visit https://github.com/bigtreetech/

### and find them yourself. If you cannot find the resources you need, you can contact our

after-sales support.

### If you encounter other problems during use, feel free to contact us, and we are answering them carefully; any good opinions or suggestions on our products are welcome, too and we will consider them carefully. Thank you for choosing BIGTREETECH. Your support means a lot to us!

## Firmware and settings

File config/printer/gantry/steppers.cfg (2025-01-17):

##################################################
##    Extruder Stepper - LDO-36STH20-1004AHG    ##
##################################################

[extruder]
microsteps: 16
full_steps_per_rotation: 200

[tmc2209 extruder]
run_current: 0.55

##################################################
##      Left B Stepper - LDO-42STH48-2004AH     ##
##################################################

[stepper_x]
microsteps: 32
rotation_distance: 40
full_steps_per_rotation: 200

[tmc2209 stepper_x]
run_current: 0.8

##################################################
##      Right A Stepper - LDO-42STH48-2004AH    ##
##################################################

[stepper_y]
microsteps: 32
rotation_distance: 40
full_steps_per_rotation: 200

[tmc2209 stepper_y]
run_current: 0.8

##################################################
##   Front Left Z0 Stepper - OMC 17HS24-2104S   ##
##################################################

[stepper_z]
microsteps: 32
gear_ratio: 80:16
rotation_distance: 40

[tmc2209 stepper_z]
run_current: 1

##################################################
##   Rear Left Z1 Stepper - OMC 17HS24-2104S    ##
##################################################

[stepper_z1]
microsteps: 32
gear_ratio: 80:16
rotation_distance: 40

[tmc2209 stepper_z1]
run_current: 0.8

##################################################
##   Rear Right Z2 Stepper - OMC 17HS24-2104S   ##
##################################################

[stepper_z2]
microsteps: 32
gear_ratio: 80:16
rotation_distance: 40

[tmc2209 stepper_z2]
run_current: 1

##################################################
##   Front Right Z3 Stepper - OMC 17HS24-2104S  ##
##################################################

[stepper_z3]
microsteps: 32
gear_ratio: 80:16
rotation_distance: 40

[tmc2209 stepper_z3]
run_current: 1

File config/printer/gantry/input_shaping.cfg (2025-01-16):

[input_shaper]
#   A frequency (in Hz) of the input shaper for X axis. This is
#   usually a resonance frequency of X axis that the input shaper
#   should suppress. For more complex shapers, like 2- and 3-hump EI
#   input shapers, this parameter can be set from different
#   considerations. The default value is 0, which disables input
#   shaping for X axis.
shaper_freq_x: 47.6

#   A frequency (in Hz) of the input shaper for Y axis. This is
#   usually a resonance frequency of Y axis that the input shaper
#   should suppress. For more complex shapers, like 2- and 3-hump EI
#   input shapers, this parameter can be set from different
#   considerations. The default value is 0, which disables input
#   shaping for Y axis.
shaper_freq_y: 33

#   If shaper_type is not set, these two parameters can be used to
#   configure different input shapers for X and Y axes. The same
#   values are supported as for shaper_type parameter.
shaper_type_x: mzv
shaper_type_y: mzv

#   Damping ratios of vibrations of X and Y axes used by input shapers
#   to improve vibration suppression. Default value is 0.1 which is a
#   good all-round value for most printers. In most circumstances this
#   parameter requires no tuning and should not be changed.
damping_ratio_x: 0.1
damping_ratio_y: 0.1

[resonance_tester]
#   A list of X, Y, Z coordinates of points (one point per line) to test
#   resonances at. At least one point is required. Make sure that all
#   points with some safety margin in XY plane (~a few centimeters)
#   are reachable by the toolhead.
probe_points: 175,175,20

#   Maximum input shaper smoothing to allow for each axis during shaper
#   auto-calibration (with 'SHAPER_CALIBRATE' command). By default no
#   maximum smoothing is specified. Refer to Measuring_Resonances guide
#   for more details on using this feature.
#max_smoothing:

#   Minimum frequency to test for resonances. The default is 5 Hz.
min_freq: 5

#   Maximum frequency to test for resonances. The default is 133.33 Hz.
max_freq: 133.33

#   This parameter is used to determine which acceleration to use to
#   test a specific frequency: accel = accel_per_hz * freq. Higher the
#   value, the higher is the energy of the oscillations. Can be set to
#   a lower than the default value if the resonances get too strong on
#   the printer. However, lower values make measurements of
#   high-frequency resonances less precise. The default value is 75
#   (mm/sec).
accel_per_hz: 75

#   Determines the speed of the test. When testing all frequencies in
#   range [min_freq, max_freq], each second the frequency increases by
#   hz_per_sec. Small values make the test slow, and the large values
#   will decrease the precision of the test. The default value is 1.0
#   (Hz/sec == sec^-2).
hz_per_sec: 1

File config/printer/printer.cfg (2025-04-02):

[virtual_sdcard]
path: /home/biqu/printer_data/gcodes

[printer]
kinematics: corexy

max_velocity: 400 
max_accel: 5700

max_z_velocity: 20
max_z_accel: 350
square_corner_velocity: 8.0

[respond]
default_type: echo
default_prefix:

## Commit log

2025-01-17 Fix duplicates and update missing configs
    [btt_ebb_sb2209_rp2040.cfg, btt_manta_mp8_v2.0.cfg, display.cfg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]
2025-01-29 Add macros and fix tap and extruder motor direction
    [btt_ebb_sb2209_rp2040.cfg, kinematics.cfg, macros.cfg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]
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2025-02-01 Fix fans and leds commands
    [display.cfg, fans.cfg, macros.cfg]
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2025-02-14 Fix chamber lights
    [leds.cfg, macros.cfg]
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2026-07-24 Sync config with machine (working post-update state)
    Pulled live from the printer (192.168.68.69) after the v0.13 update; the
    machine config was the last-known-good and had drifted from the repo.
    - EBB SB2209: rename fan aliases so HOTEND_FAN=gpio14, PARTS_FAN=gpio13
    (was gpio13/gpio14). Net physical wiring is unchanged; the [fan] /
    [heater_fan hotend_fan] pin assignments were swapped to match.
    - stealburner/fans.cfg: [fan]->EBB:PARTS_FAN, hotend_fan->EBB:HOTEND_FAN;
    add commented tachometer_pin/hardware_pwm hints.
    - stealburner/extruder.cfg: pressure_advance_smooth_time 0.04 -> 0.03.
    - stealburner/leds.cfg: pin EBB:gpio16 -> EBB:RGB (same pin, named alias).
    - klippy.conf: capture SAV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
    [btt_ebb_sb2209_rp2040.cfg, extruder.cfg, fans.cfg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]
2026-07-24 Fix min_extrude_temp conflict and CAN_L alias typo
    Two config issues found while syncing the repo to the machine:
    - min_extrude_temp was defined twice for [extruder]: 190 in
    stealburner/extruder.cfg and 160 in stealburner/heatend.cfg. Klipper
    merges duplicate sections with last-loaded-wins, and includes are
    sorted, so heatend.cfg's 160 was the effective value (confirmed
    against the running machine via Moonraker). Removed the shadowed 190
    so the file no longer contradicts actual behavior. No behavior change.
    - mcu/btt_ebb_sb2209_rp2040.cfg had CAH_L=gpio5 in aliases_canbus, so
    the following CAN_TX=CAN_L referenced an undefined alias. Harmless
    today since CAN uses canbus_uuid a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
    [btt_ebb_sb2209_rp2040.cfg, extruder.cfg]
2026-07-24 Phase 0: resolve silent config conflicts, add linter and tuning plan
    Klipper merges duplicate sections with RawConfigParser(strict=False) and
    sorted, non-recursive includes -- so duplicates silently merge and the last
    file loaded wins. Several settings were therefore accidental rather than
    chosen. Verified every effective value against the running machine.
    Conflicts resolved:
    - Z run_current was z=1.0 / z1=0.8 / z2=1.0 / z3=1.0. stepper_drivers.cfg
    set 0.8 for x/y/z/z2/z3 (no z1 entry) and steppers.cfg then overrode
    z/z2/z3 to 1, leaving the rear-left corner 20% low. All four are now
    0.9A (43% of the OMC 17HS24-2104S 2.1A rating; Ellis: 40-50% to start).
    stepper_drivers.cfg is now t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
    [btt_manta_mp8_v2.0.cfg, heatend.cfg, input_shaping.cfg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]
2026-07-24 Rework Phase 1 for a fast-turnaround print workflow
    The original Phase 1 (mesh every print + 45-60 min soak) was workflow-blind:
    it imposes an hour of setup on parts that print in 5-10 min. Ellis' 'at least
    an hour' is cold-start advice, not a per-session cost.
    Revised around gating on measured temperature instead of elapsed time.
    TEMPERATURE_WAIT returns immediately when the sensor is already in range and
    accepts passive temperature_sensor objects (verified in heaters.py), so a warm
    machine waits zero seconds while a cold one still soaks properly.
    Tier A (no hardware): adaptive meshing (ADAPTIVE=1, confirmed supported in
    v0.13) so a small centred part probes only its own footprint; temper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
2026-07-25 Implement Phase 0.5 and Tier A; add ADRs
    Phase 0.5 -- delete the local PAUSE/RESUME/CANCEL_PRINT, which never ran
    because mainsail.cfg defines all three and is the last include. Reattach the
    genuinely missing behaviour via _CLIENT_VARIABLE in a new
    macros/client_variables.cfg: filament sensor disable/restore on pause/resume,
    and cancelling a heat soak on cancel. Deliberately does not call PRINT_END
    from _USER_CANCEL -- mainsail already handles heaters/fan/retract/park.
    Tier A -- PRINT_START previously ran no heat soak at all: it computed
    heatsoack_duration, printed it in a status message, and then ran the same
    M190 in both branches while the real HEAT_SOAK call sat commented out.
    Replaced w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
    [aux_temperature_sensors.cfg, client_variables.cfg, printer.cfg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]
2026-07-25 Fix standby guard: use print_stats.state, not idle_timeout.state
    Smoke-testing STANDBY_WARM/STOP_STANDBY_WARM on the machine showed the bed
    still targeting 95C after STOP_STANDBY_WARM returned OK.
    Cause: the guard was 'idle_timeout.state != PRINTING'. idle_timeout.state is
    a BUSY flag, not a job flag -- Klipper sets it to Printing while executing any
    command, including the guarding macro itself. So the condition was always
    false at the exact moment it mattered and M140 S0 never ran, leaving the bed
    latched on. Guarding on print_stats.state instead.
    Verified on the machine after the fix: STOP_STANDBY_WARM releases the bed
    (95 -> 0), and the delayed_gcode auto-expiry releases it unattended a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
    [standby.cfg]
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2026-07-25 Add PowerShell MCU firmware updater; document why Moonraker cannot do it
    scripts/Update-VoronMcuFirmware.ps1 compares each MCU's firmware against the
    Klipper host version via Moonraker and flashes only genuine mismatches, so it
    is a safe no-op when everything is current -- which is what makes it
    practical to run after every 'update all'.
    Verified against the real machine: parse-clean under pwsh, dry run correctly
    identified ebb/manta as current and linux as needing work, and a full
    non-dry-run with both CAN boards up to date made no changes and left Klipper
    ready.
    Encodes the safety rules learned during the manual reflash: refuses to run
    while printing or paused, fixed board order with the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
2026-07-25 Complete Linux MCU update; make the script handle it autonomously via root
    All three MCUs now run v0.13.0-708-g7046bd00e and Klipper reports zero
    config warnings (down from 6 deprecated_mcu_code).
    The Linux MCU install needs root only for copying the ELF into
    /usr/local/bin. With a root key now authorized, the script does this itself:
    Test-RootSsh probes for key-based root and Install-LinuxMcu replicates
    klipper's scripts/flash-linux.sh (stop services, replace binary, restart),
    backing up the outgoing binary first so the change is reversible. Without
    root it falls back to staging plus printed instructions, so the script still
    works on hosts where root is not available.
    Fixes a real bug the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
2026-07-25 Fix thermal gate after live print test exposed three real bugs
    Ran the full pipeline on the machine. Verified working: PROBE_ACCURACY std
    dev 0.001858 / range 0.005 (Ellis' bar is 0.004 / 0.0125), QGL converged
    0.0437 -> 0.005, mesh completed and saved, and the _USER_CANCEL hook fired
    ('Standby cancelled') which confirms the Phase 0.5 _CLIENT_VARIABLE wiring
    works live.
    Three bugs the test exposed, all mine:
    1. The exhaust fan fought the gate. PRINT_START runs M141 S{CHAMBER} (36 from
    the slicer) before the gate, and a [temperature_fan] runs its fan ABOVE its
    target -- so the fan sat at speed 1.0 cooling the chamber while the gate
    waited for 40c. The gate now raises the exhaust ta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
    [printing.cfg]
2026-07-25 Enable Moonraker object preprocessing; preheat and circulate during soak
    Cura does not emit EXCLUDE_OBJECT_DEFINE, so BED_MESH_CALIBRATE ADAPTIVE=1
    was silently falling back to a full 121-point mesh on every print. Moonraker
    bundles preprocess_cancellation and can inject the definitions itself -- it
    was simply off, since moonraker.conf had no [file_manager] section at all.
    Enabled it and verified empirically: the same Cura file went from 0 to 36
    EXCLUDE_OBJECT_DEFINE entries with correct polygon bounds. Cura can stay.
    Two soak improvements, both from the user and both borne out by the test run:
    - Start the hotend at 150c right after M190 rather than waiting for the QGL
    preheat. Measured: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
    [printing.cfg]
2026-07-25 Hold chamber exhaust above the soak gate during warm-up; fix PRINT_END
    Monitored a full print end to end. Adaptive meshing now works: 'Found 1
    objects', bounds shrunk to the part (159-190 in X and Y), 'Adapted probe
    count: (3,3)' -- 9 probe points instead of 121, and the mesh took 44s instead
    of roughly 12 minutes.
    Three fixes from what the run showed:
    - The chamber exhaust (MP8:FAN3) was still venting through the entire bed
    warm-up, because M141 was set to the slicer's CHAMBER value (36) at the top
    of PRINT_START and only raised inside the gate block. The chamber sat at
    ~38c the whole time. It is now held at max(slicer target, gate + 10) from
    the start, and only returns to the sli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
    [printing.cfg, standby.cfg]
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2026-07-25 Correct Z belt reading: 7.2 mm, in spec
    The Z value was 7.2 mm, not the 9.5-9.8 used in the previous commit.
    Z 7.2 mm -> 21.53 N against BTT's 20.4-25.8 N window -> IN RANGE
    Both belt sets are therefore in spec and no belt work is needed. Retracts the
    over-tension finding and the suggestion that Z belts contributed to the mesh
    saddle -- belt tension is now ruled out, leaving gantry squaring, debris under
    the spring steel and bed mounting as the Phase 2 suspects.
    The method disagreement is unaffected, since it does not depend on the reading:
    this printer's actual tensions correspond to roughly 207 Hz on Z and 156 Hz on
    A/B over a 150 mm span, against the frequency tool's 140 Hz target.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
2026-07-25 Cut PRINT_START dead time; fix nozzle re-oozing during the wipe
    Instrumented a full warm-start print. PRINT_START went 927s -> 365s versus the
    pre-fix run, with STANDBY_WARM confirmed working (bed held at 100c, so M190
    returned in ~2s instead of 355s) and the chamber gate costing zero seconds
    because the chamber was already at 44c.
    Measured phase breakdown of the 365s:
    home 40.7s
    pre-QGL 94.3s (0.626 -> 0.035 -> 0.0075)
    M190 ~2s (was 355s before STANDBY_WARM)
    CLEAN_NOZZLE 48.7s (~46s of it just waiting for the hotend)
    QGL preheat 20.9s
    QGL #2 58.9s
    adaptive mesh 49.3s (3x3, 9 points)
    hotend + purge 38.7s
    Two fixes f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
    [clean_nozzle.cfg, printing.cfg]
2026-07-25 Make ADR upkeep a repo rule; backfill drift and two missing records
    Adds CLAUDE.md so the rule is picked up automatically, with ADR upkeep as Rule 1:
    every decision gets a record written in the same change, every drift updates the
    existing record's Revisions section with the evidence that forced it, and a
    reversal gets a superseding ADR while the old reasoning stays intact. Also
    codifies verify-against-the-machine, run the linter, one owner per config
    section, and the physical-safety checks (TAP probe, clear plate, Manta last).
    Backfills the drift accumulated over the last few rounds:
    0003 soak gate - exhaust fan fighting the gate, gate relocated after QGL,
    unbounded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
    [printing.cfg, standby.cfg]
2026-07-25 Show standby on the LEDs and chamber temp on the print screen
    Standby now signals itself. After ADR-0005 the printer holds the bed at ~100c
    and keeps the steppers energised between prints, but PRINT_END ended with
    Status_Off, so a hot, powered machine looked identical to a cold, off one --
    the wrong signal on something you reach into to swap parts. STANDBY_WARM now
    sets STATUS_READY, which already maps to a colour literally named 'standby' in
    _sb_vars, and PRINT_END re-asserts it after its own Status_Off. Expiry and
    STOP_STANDBY_WARM clear it. The LEDs are lit exactly while the bed is hot and
    the motors are held.
    Chamber temperature on the print screen took some digging:
    - display.cfg is d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
    [fans.cfg, printing.cfg, standby.cfg]
2026-07-25 Fix KlipperScreen error banner: no brackets allowed, even in comments
    Adding titlebar_items raised 'Section headers have extra information after
    brackets possible newline issue'. Klipper was never affected -- 0 warnings and
    the print continued -- the banner came from KlipperScreen's own validator in
    ks_includes/config.py, which scans the raw file for any content followed by a
    closing bracket and one more character, without skipping comment lines. The
    comment added next to the setting named a config section in brackets, which was
    enough to trip it.
    The first fix attempt quoted the offending regex in a replacement comment and
    tripped the same check, so the rule is now stated plainly: no squar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
2026-07-25 Plan: record the measured PRINT_START result, 927s -> 219s
    Run 3 confirmed the warm-chain path end to end. With the previous print ending
    inside the 25 min standby window, PRINT_START skipped homing (still homed),
    skipped the pre-QGL (quad_gantry_level.applied survived because PRINT_END held
    the motors), spent 0s on M190 (bed held at 100c) and 0s on the soak gate
    (chamber already 47.5c). It reached QGL at 75.8s where the previous cold-ish run
    took 252.1s.
    Adds the measured phase table for both paths and lists the remaining levers in
    size order: probe samples 3->2 (~15s), the ooze-pull no-op in CLEAN_NOZZLE
    (~20s), the G4 P120000 party dwell in PRINT_END (2 min), and the duplicate G28 Z
    (~10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
2026-07-25 Four PRINT_START/END time fixes: samples, ooze-pull, party dwell, duplicate Z home
    1. [probe] samples 3 -> 2. The adaptive mesh is 9 points but samples multiply
    that into 27 probe cycles. Measured PROBE_ACCURACY std dev is 0.001858mm, so
    the standard error of the mean moves from ~0.0011 to ~0.0013mm -- 0.0002mm
    against a ~0.02mm first-layer sensitivity. Roughly 15s back.
    2. CLEAN_NOZZLE's 40mm/120mm-per-min climb now only runs when a purge actually
    happened. It exists to stretch a molten string until it snaps, which needs
    pressure behind the nozzle; on the no-purge path PRINT_START uses it was 20s
    of moving slowly for nothing. The no-purge branch just clears the tube at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
    [clean_nozzle.cfg, leds.cfg, printing.cfg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]
2026-07-25 Fix cross-macro variable that cancelled a finished print; teach the linter
    PRINT_END used {party_seconds} while variable_party_seconds was declared on
    PRINT_START. Klipper scopes a macro's variable_* to that macro only, so it
    rendered as an empty string and emitted 'UPDATE_DELAYED_GCODE ID=_PARTY_FINISH
    DURATION=', which failed to parse. The error aborted PRINT_END and Klipper
    marked an otherwise finished print as cancelled -- filament used was 1218mm
    against 1219mm for the completed run, so the part itself printed fine.
    Moved the declaration onto PRINT_END, where it is used.
    This class of bug is invisible at config load and only shows up at runtime, so
    the linter now has a cross-macro-var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
    [printing.cfg]
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2026-07-26 Re-run input shaping; fix wrong adxl axes_map and a CAN-induced MCU shutdown
    Two root causes had to be fixed before the measurement meant anything.
    The adxl345 axes_map was the default x,y,z, but a stationary ACCELEROMETER_QUERY
    reported gravity (~9550) on the sensor's X axis -- Klipper was told sensor-X was
    printer-X while it actually pointed up. BTT's official sample config for this
    board specifies axes_map z,-y,x. After the fix gravity reads 9474.6 on the third
    value as it should. The old shaper values were measured through that wrong
    mapping AND at probe_points 100,100 rather than bed centre; both were inherited
    from the same BTT sample, which targets a smaller printer.
    The first sweep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
    [btt_ebb_sb2209_rp2040.cfg, input_shaping.cfg]
2026-07-26 Add Z-axis resonance diagnostic; record gantry cross-coupling finding
    Ran TEST_RESONANCES AXIS=Z as a gantry diagnostic, not to configure a Z shaper
    (this machine has none and should not -- Z moves are slow and short, and surface
    artifacts come from X/Y).
    Two config facts had to be dealt with first:
    - accel_chip covers the xy pair ONLY. resonance_tester.py reads a separate
    accel_chip_z that defaults to empty, because Klipper allows a different,
    often bed-mounted sensor for Z and will not assume. Without it the test fails
    with "No accelerometers specified that can measure resonances over axis z".
    Added accel_chip_z pointing at the same physical ADXL.
    - Klipper's Z defaults (accel_pe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
    [input_shaping.cfg, resonances_z_2026-07-26.csv]
2026-07-26 Correct the Z resonance interpretation: the Y coupling was a noise floor
    The previous commit read a 27% Z-to-Y cross-coupling out of this data and took it
    as evidence that the gantry pitches front-to-back, on the same axis as the
    0.1487mm mesh saddle. Re-checking the ratio across frequency instead of peak to
    peak shows that is wrong.
    mean psd_y/psd_z at the 53Hz mode (+-4Hz) : 0.28
    mean psd_y/psd_z away from it : 0.36
    The coupling is HIGHER away from the mode than at it, and the ratio climbs past
    1.0 around 59-61Hz precisely where psd_z has decayed to ~13% of peak. That is the
    signature of a noise floor -- roughly constant Y noise divided by a falling Z
    signal -- not a coup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
2026-07-26 Plan: gantry squaring confirmed done; reframe the mesh saddle
    Owner confirmed the gantry is already squared, which closes the last mechanical
    suspect alongside belt tension (in spec, three independent confirmations
    including the resonance sweep showing only 1% of energy below 30Hz).
    Reframes what the 0.1487mm saddle means. QGL corrects a PLANE and cannot correct
    curvature, and the measured shape is a saddle -- middle of Y low, both ends high.
    No amount of QGL or squaring removes that; compensating it is exactly what bed
    mesh is for. With belts and squaring both ruled out, the remaining deviation is
    almost certainly the bed assembly itself: plate flatness plus mounting.
    Since adaptive meshi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
2026-07-26 Open the slicer gate: M201/M203 shims plus a verified setup profile
    Audited what a PrusaSlicer-lineage slicer can emit and found two more
    unimplemented gcodes beyond M205: M201 (max acceleration) and M203 (max
    feedrate). Both appear when "emit machine limits to gcode" is enabled and both
    would have raised Unknown command and aborted the print. Added as
    accept-and-ignore shims, deliberately not mapped onto SET_VELOCITY_LIMIT --
    machine limits belong in the Klipper config, and a slicer silently lowering them
    mid-print is worse than ignoring the command.
    Verified live that every gcode such a slicer emits now succeeds: M201, M203,
    M204, M205, G11, M900, M73, M221. G10 returned an error which tu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
2026-07-30 Calibrate extruder, squish and Z offset; open the OrcaSlicer gate
    Ellis' tuning sequence through first-layer squish, plus the four ADRs that were
    owed for work already in the tree.
    Measured on the machine, not inferred:
    - Extruder rotation_distance 22.780000 -> 22.460000. Ellis' method (120mm mark,
    100mm push, hot, no disassembly -- the guide calls teardown optional and
    calibrates hot itself). First pass 98.60/100mm; confirmation pass with the new
    value 99.5/100mm, i.e. 1.4% -> 0.5%, consistent and within mark/caliper noise.
    Klipper caps extrude-only moves at 50mm, so the push is two G1 E50.
    - probe z_offset -0.514 -> -0.449, in two stages. Paper test per Klipper's
    official meth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
2026-07-31 Pressure advance 0.055 -> 0.022; fix z-hop disabled too broadly
    PA measured with OrcaSlicer's PA Pattern method (Ellis' preferred), ABS, 41
    blocks 0 -> 0.08 in 0.002 steps at 120mm/s / 3000mm/s^2. Block 11 from the left
    read best: corners uniform, no bulge from too little PA, no gap from too much.
    The old 0.055 was inherited and never measured -- the real value is less than
    half of it. PA is filament-specific; 0.022 is the ABS number and stands as the
    machine default since ABS is what this printer runs.
    Also fixes a mistake in the OrcaSlicer profile from the previous commit. The
    plan item reads "disable z-hop on the FIRST LAYER"; the profile set z_hop: 0
    globally. With no lift on any layer,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
2026-07-31 Standby holds 85% of the print bed target instead of 100%
    PRINT_END now calls STANDBY_WARM TEMP={bed_was * standby_factor} with
    standby_factor 0.85, so a 105c print stands by at 89c.
    This partly walks back ADR-0005, which argued for the full print temperature and
    explicitly rejected a lower plateau. That reasoning is left intact in the ADR
    because the concern is still valid -- the trade is that 85% is a far smaller sag
    than the 60-70c the original text was arguing against (~15% vs ~38%), while
    cutting energy and the unattended-heater exposure of holding a 350mm bed at full
    ABS temperature for up to 25 minutes. Owner's call rather than a measurement, and
    the ADR records it as such; the origi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
2026-07-31 Record flow ratio calibration: 0.926 -> 0.9334 (ABS)
    Extrusion multiplier via OrcaSlicer's Flow Rate calibration. Slicer-side only --
    Klipper has no extrusion multiplier (M221 is a runtime override), so this lives
    in the filament profile and changes no config here. Recorded in TUNING_PLAN and
    in slicer_profiles/README so the value is not carried in someone's memory.
    Took three prints, and the detour is the part worth keeping:
    Pass 1 base 0.926 -> picked +10 = 1.019
    Pass 2 base 1.019 -> EVERY block over-extruded, even -9. Base too high.
    Pass 2 base 0.9723 -> -7/-6 gaps, -5 clean, chose -4 = 0.9334 for margin
    Two causes, both worth remembering:
    - Pass 2 spans -9..0, NOT +/-9.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
2026-08-04 Confirm z_offset -0.609 via fine squish grid; fix purge/prime line
    z_offset: -0.609 verified as the optimum first-layer squish contact:
    - Sign fix from 2026-07-30 (+0.08 winner baked the wrong way, -0.449 crushed
    first layers, prints short 0.3-0.5mm). Klipper source: Z_OFFSET_APPLY_PROBE
    new = z_offset - offset -> -0.529 - 0.08 = -0.609.
    - 25mm bordered squish squares: center baseline best pattern; a -0.04mm
    more-squish candidate (-0.569) over-squished every square (raised line
    borders) and was reverted. Final Z_STEP=0.002 grid (center +-0.008mm)
    confirmed center square = delta 0 = best. No further change.
    - Join gaps at correct squish judged a flow/PA artifact, not a Z issue.
    SQU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
2026-09-19 Refuse slicer preheat, heat bed early, fix M190 cool-down wait, wait for probe temp before cold QGL
    Measured on klippy.log 2026-09-18/19: gcode sliced with a 3mf-embedded Orca
    profile emitted M190/M109 before PRINT_START, costing ~3.3 min per print
    (74-84 s to 260c, then 90-120 s uncancellable cool-down for TAP) and ending
    in an emergency stop when a cancel could not land. PRINT_START now raises an
    error on entry if the hotend target is already above 150c (ADR-0017).
    Sequence changes (ADR-0003 revision, ADR-0019):
    - M140 issued at the top next to M104 150: a cold bed took 330 s and none of
    it overlapped homing/pre-QGL.
    - M190 override waits MINIMUM only; the old MAXIMUM=s+1 blocked a 55c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
2026-11-09 Cool the EBB board: temperature_fan on its IND/FAN header (ADR-0020)
    The EBB shut down with 'Timer too close' at 78.5 C board temp (chamber 46.6 C)
    after 2h17 of ABS on 2026-09-20; rx_error 0 -> 11049 on the EBB only, host and
    bridge bus counters clean. A 24 V fan on GPIO6 now runs as [temperature_fan EBB]
    (target 50, watermark +-3, max_temp 100), replacing [temperature_sensor EBB].
    Deployed and verified live 2026-09-22.
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
